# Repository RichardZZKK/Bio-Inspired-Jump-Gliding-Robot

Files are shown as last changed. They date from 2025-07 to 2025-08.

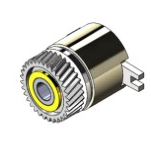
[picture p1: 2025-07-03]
motor-to-electromagnetic clutch connection design/Assembled servo.png

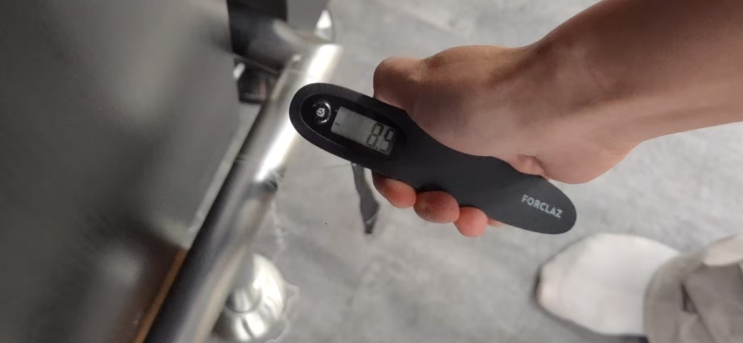
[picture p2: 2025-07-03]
photos taken during the project/testing the maximum tensile strength in 0.5mm.jpg

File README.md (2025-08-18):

# Bio-Inspired-Jump-Gliding-Robot

Inspired by recent studies of planetary jump robots and bio-inspired gliding mechanisms, we propose a novel robot capable of both repeated elastic-powered jumps and controlled gliding. The key innovation is the use of carbon fiber strips for energy storage and actuation, enabling jumping launches and mid-air wing deployment. So far, we detail the system architecture, mathematical modeling, and challenges encountered in the realization of this hybrid jump-gliding robot.

Our main goal was to design a robot capable of repeated jumps and gliding, expanding its operational range and adaptability. Our innovation lies in the integration of a carbon fiber strip-powered jumping mechanism with a deployable wing gliding system. Unlike prior robots that typically perform single-use or limited jumps, and compared to conventional flying robots, our design offers higher reliability and significantly lower energy consumption. So far, we detail the system architecture, mathematical modeling, and challenges encountered in the realization of this hybrid jump-gliding robot.

# So far, we have completed the following work...

<span style="font-size:20px;">And further tasks are ongoing and being continuously updated until the project is completed.</span>

[Interm Review PPT 01](https://sutdapac-my.sharepoint.com/:p:/g/personal/zheng_zhang_mymail_sutd_edu_sg/EfePilspKQ1Gtsf8nFOdvJUBf0UiOSyuQf-EtbSmFA2OlQ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)

[Interm Technical Report 01](https://github.com/RichardZZKK/Bio-Inspired-Jump-Gliding-Robot/blob/main/Interim%20Technical%20Report%2001.pdf)

[Final PPT](https://github.com/RichardZZKK/Bio-Inspired-Jump-Gliding-Robot/blob/main/Final%20Presentation.pdf)

[Final Technical Report 01](https://github.com/RichardZZKK/Bio-Inspired-Jump-Gliding-Robot/blob/main/Final%20Technical%20Report.pdf)

- Jump Solution Selection: After comparing different jump actuation mechanisms, we found that biomimetic legged or complex multi-link jumping structures, are not suitable for our intended application. These mechanisms are generally too heavy and not conducive to achieving lightweight design and effective gliding. Based on further research, we selected the carbon fiber strip compression jumping mechanism, which best meets our requirements for both performance and weight.

<div align="center">
<table>
  <tr>
    <td>
      
    </td>
    <td>
      
    </td>
  </tr>
</table>
</div>

<p align="center">
  
</p>
  
- Release Mechanism: The release mechanism works by using an electromagnetic clutch* to quickly connect or disconnect the winch from the motor. During energy storage, the motor—through the engaged clutch—pulls the UHMWPE line to stretch the carbon fiber strip and store elastic energy. When the target tension is reached, power to the clutch is cut, instantly disconnecting the winch from the motor. This allows the stored energy to be released rapidly, enabling the jump, while protecting the motor from any sudden forces or backlash during the release.
<div align="center">
<table>
  <tr>
    <td>
      
    </td>
    <td>
      
    </td>
  </tr>
</table>
</div>

- Design of Jump Energy Storage and Release: Utilizes a winch motor to tension a Ultra-high-molecular-weight polyethylene(UHMWPE) line attached to carbon fiber strips, storing elastic potential energy. 
<div align="center">
<table>
  <tr>
    <td>
      
    </td>
    <td>
      
    </td>
  </tr>
</table>
</div>

- Design of Gliding Mechanism: Wings are deployed at the apex of each jump, either by electronic control or mechanical triggering.
*An electromagnetic clutch engages or disengages power transmission between two shafts by using electromagnetic force. When current is applied, the clutch connects the shafts; when current is removed, the connection is released.
<div align="center">
<table>
  <tr>
    <td>
      
    </td>
    <td>
      
    </td>
  </tr>
</table>
</div>

<div align="center">
<table>
  <tr>
    <td>
      
    </td>
    <td>
      
    </td>
  </tr>
</table>
</div>

## Electronics Design

### MCU & Power

- **MCU**: Arduino Nano 33 BLE Sense Rev2 (NINA B306 + Cortex‑M4F)  
- **Input Voltage**: 3.3 V (all I/O 3.3 V TTL)  
- **Key Specs**: 64 MHz, 1 MB Flash + 256 kB RAM; BLE 5.0; onboard DC‑DC converter; BMI270/BMM150 9‑axis IMU  
- **Power Supply**:  
  - **Motor**: 2 × 3.7 V, 100 mAh Li‑ion battery packs in series  
  - **Clutch**: 5 × 3.7 V, 100 mAh Li‑ion battery packs in series  
  - **Board**: 1 × 3.7 V, 100 mAh Li‑ion battery pack

### Bill of Materials

| # | Component |
|---|---|
| 1 | Arduino Nano 33 BLE Sense Rev2 |
| 2 | On‑board 9‑axis IMU (BMI270 + BMM150) |
| 3 | 6 V DC motor + MOSFET driver |
| 4 | 24 V electromagnetic clutch + MOSFET driver |
| 5 | 2 × Hobby servos |
| 6 | Power modules (3.3 V, 6 V, 24 V rails) |
| 7 | Assorted wiring |

### Pin Assignment

| Function | Arduino Pin  | Description |
|---|---|---|
| Motor MOSFET Gate | D3 | Drives 6 V DC motor |
| Clutch MOSFET Gate | D4 | Drives 24 V electromagnetic clutch |
| Servo PWM Signals | D9, D10 | Hobby servo control (future gliding) |
| Limit Switch Inputs | D2, D5… | End‑stop switches |
| I²C (BMI270 IMU) | SDA(A4), SCL(A5) | On‑board 9‑axis sensor |
| BLE UART | Serial1 | UART on NINA B306 (debug/servo) |
| Power & Ground | VIN, GND | 3.3 V input & common ground |

---

### Code Overview
#### File Structure

```plaintext
src/
└── Jump-Gliding-Robot/
    ├── Jump-Gliding-Robot.ino    # Main application entrypoint
    ├── include.h                 # Macros & Lobot protocol constants
    └── SerialServo.h             # Lobot serial‑servo driver implementations
```

Below is an annotated overview of `Jump-Gliding-Robot.ino`.  

#### 1. Include Statements & Libraries

```cpp
#include <ArduinoBLE.h>
#include "Arduino_BMI270_BMM150.h"
#include <Wire.h>
#include <Servo.h>
#include "include.h"
#include "SerialServo.h"
```
* ArduinoBLE: BLE Low Energy support
* Arduino_BMI270_BMM150: On‑board 9‑axis IMU (BMI270 + BMM150)
* Wire: I²C bus for IMU
* Servo: Hobby servo control
* include.h / SerialServo.h: Project‑specific macros & Lobot servo driver

#### 2. Global Objects & Configuration
```cpp
Servo servo1, servo2;

BLEService sensorService("180F");
BLEByteCharacteristic servoCommandCharacteristic("2A19", BLEWrite);
BLECharacteristic imuDataCharacteristic("2A58", BLENotify, 36);

const int motorPin   = 3;       // MOSFET gate for 6 V motor
const int clutchPin  = 4;       // MOSFET gate for 24 V clutch
const long interval  = 50;      // IMU send interval (ms)
unsigned long previousMillis = 0;
```
* servo1/servo2: Reserved for future gliding control
* BLEService & Characteristics:
* 2A19 (write) for receiving commands
* 2A58 (notify) for streaming IMU data
* Pins & Timing: Define motor/clutch pins and non‑blocking timer

#### 3. setup() — Initialization
```cpp
void setup() {
  Serial1.begin(115200);
  Wire.begin();
  servo1.attach(9);
  servo2.attach(10);

  pinMode(motorPin, OUTPUT);
  pinMode(clutchPin, OUTPUT);
  digitalWrite(motorPin, LOW);
  digitalWrite(clutchPin, LOW);

  if (!BLE.begin()) while (1);
  BLE.setLocalName("Nano33BLE_IMU");
  BLE.setAdvertisedService(sensorService);
  sensorService.addCharacteristic(servoCommandCharacteristic);
  sensorService.addCharacteristic(imuDataCharacteristic);
  BLE.addService(sensorService);
  BLE.advertise();

  if (!IMU.begin()) while (1);
}
```
* Serial & I²C: Serial1 for debugging/servo, Wire for IMU
* Servo Pins: Attach D9/D10
* Motor/Clutch: Initialize outputs to LOW
* BLE: Start, configure service & characteristics, begin advertising
* IMU: Begin BMI270/BMM150 sensor

#### 4. sendIMUData() — Packaging & Sending IMU
```cpp
void sendIMUData() {
  float ax, ay, az, gx, gy, gz, mx, my, mz;

  if (IMU.accelerationAvailable())    IMU.readAcceleration(ax, ay, az);
  if (IMU.gyroscopeAvailable())       IMU.readGyroscope(gx, gy, gz);
  if (IMU.magneticFieldAvailable())   IMU.readMagneticField(mx, my, mz);

  byte imuData[36];
  memcpy(imuData +  0, &ax, 4);
  memcpy(imuData +  4, &ay, 4);
  memcpy(imuData +  8, &az, 4);
  memcpy(imuData + 12, &gx, 4);
  memcpy(imuData + 16, &gy, 4);
  memcpy(imuData + 20, &gz, 4);
  memcpy(imuData + 24, &mx, 4);
  memcpy(imuData + 28, &my, 4);
  memcpy(imuData + 32, &mz, 4);

  imuDataCharacteristic.writeValue(imuData, 36);
}
```
* Selective Reads: Only read available axes
* Data Layout: ax, ay, az, gx, gy, gz, mx, my, mz (4 bytes each)
* Notify: Send 36 bytes over BLE

#### 5. loop() — Main Command Handler
```cpp
void loop() {
  BLEDevice central = BLE.central();
  if (!central || !central.connected()) return;

  byte command = 0;
  if (servoCommandCharacteristic.written()) {
    command = servoCommandCharacteristic.value();
  }

  if (command == 1) {
    // Pull rope & release for jumping
    digitalWrite(motorPin, HIGH);
    digitalWrite(clutchPin, HIGH);
    delay(5000);
    digitalWrite(motorPin, LOW);
    digitalWrite(clutchPin, LOW);
  }
  else if (command == 2) {
    // Test mode: keep motor & clutch powered
    digitalWrite(motorPin, HIGH);
    digitalWrite(clutchPin, HIGH);
  }
  else if (command == 3) {
    // Future gliding: move servos
    LobotSerialServoMove(Serial1, 1, 400, 800);
    LobotSerialServoMove(Serial1, 2, 400, 800);
  }
  else if (command == 4) {
    // Future gliding: move servos
    LobotSerialServoMove(Serial1, 1, 800, 400);
    LobotSerialServoMove(Serial1, 2, 800, 400);
  }

  // Periodic IMU report
  if (millis() - previousMillis >= interval) {
    previousMillis = millis();
    sendIMUData();
  }
}
```
* Checks BLE connection
* Non‑blocking command read & dispatc
* Jump sequence, test mode, future gliding
* Periodic IMU data send

# Ongoing efforts focus on: 
* Improving mechanical efficiency and alignment, 
* Optimizing the wing deployment strategy, 
* Designing and testing closed-loop feedback and control, 
* Validating the robot in more varied and realistic test scenarios.

Authors:
[RichardZZKK](url)
[llz077](url)
[Ianthomas-gee](url)

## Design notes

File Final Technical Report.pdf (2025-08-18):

# A Bio-Inspired Jump-Gliding Robot for Planetary and Terrestrial Exploration

Final Technical Report
Zhang Zheng, Liu Lizhi, Xu Yukun
Engineering Product Development, Singapore University of Technology and Design Singapore
zheng_zhang@mymail.sutd.edu.sg lizhi_liu@mymail.sutd.edu.sg yukun_xu@mymail.sutd.edu.sg

Abstract—Inspired by recent studies of planetary jump robots and bio-inspired gliding mechanisms, we propose a novel robot capable of both repeated elastic-powered jumps and controlled gliding. The key innovation is the use of carbon fiber strips for energy storage and actuation, enabling jumping launches and mid-air wing deployment. So far, we detail the system architecture, mathematical modelling, and challenges encountered in the realization of this hybrid jump-gliding robot.
Index Terms—Jump-gliding robot; elastic-powered jumping; carbon fiber; gliding mechanism.
I. INTRODUCTION
Our main goal was to design a robot capable of repeated jumps and gliding, expanding its operational range and adaptability. Our innovation lies in the integration of a carbon fiber strip-powered jumping mechanism with a deployable wing gliding system. Unlike prior robots that typically perform single-use or limited jumps, and compared to conventional flying robots, our design offers higher reliability and significantly lower energy consumption. So far, we detail the system architecture, mathematical modeling, and challenges encountered in the realization of this hybrid jump-gliding robot.

II. SYSTEM DESIGN
Solution Selection: After comparing different jump actuation mechanisms, we found that biomimetic legged or complex multi-link jumping structures are not suitable for our intended application. These mechanisms are generally too heavy and not conducive to achieving lightweight design and effective gliding. Based on further research, we selected the carbon fiber strip compression jumping mechanism, which best meets our requirements for both performance and weight. Release Mechanism: The release mechanism works by using an electromagnetic clutch* to quickly connect or disconnect the winch from the motor. During energy storage, the motor— through the engaged clutch—pulls the UHMWPE line to stretch the carbon fiber strip and store elastic energy. When the target tension is reached, power to the clutch is cut, instantly disconnecting the winch from the motor. This allows the stored energy to be released rapidly, enabling the jump, while protecting the motor from any sudden forces or backlash during the release.
Design of Jump Energy Storage and Release: Utilizes a winch motor to tension an Ultra-high-molecular-weight polyethylene (UHMWPE) line attached to carbon fiber strips, storing elastic potential energy.
Electromagnetic Clutch
For the release mechanism, we employed an electromagnetic clutch to control the tightening and release of the Ultra-high-molecular-weight polyethylene (UHMWPE). To ensure proper alignment of the UHMWPE during retraction, a dedicated holder frame (Fig. 1) was designed to accommodate both the servo motor and the electromagnetic clutch.

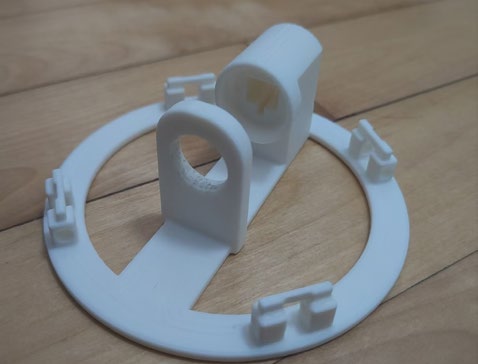
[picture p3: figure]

Fig. 1. Holder frame
In addition, a secondary frame was introduced to support the winch shaft, enabling it to counteract the downward tensile force exerted by the rope. Overall, the servo motor is rigidly connected to the electromagnetic clutch via a coupling component (Fig. 2.), and both are mounted within the frame. The gear portion of the clutch is exposed externally (Fig. 3.), where it engages with a custom-designed internal-toothed shaft connector. This shaft passes through a bearing, which is secured on the secondary frame (Fig. 4.). The shaft itself is designed with a small through-hole (Fig. 5.), through which the UHMWPE is threaded and fixed by knotting, enabling controlled winding and unwinding.

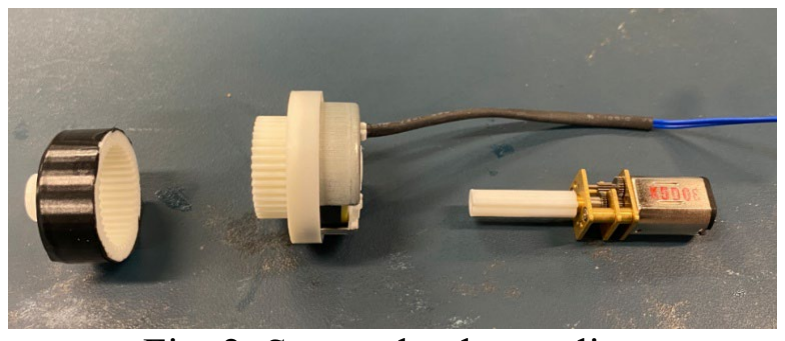
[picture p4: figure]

Fig. 2. Servo-clutch coupling

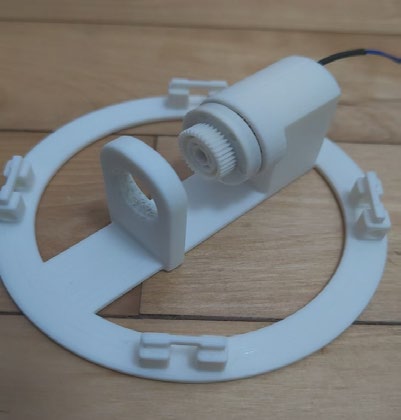
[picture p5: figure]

Fig. 3. Clutch placement

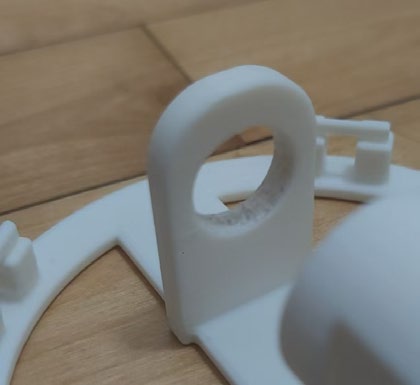
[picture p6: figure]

Fig. 4. Bearing support

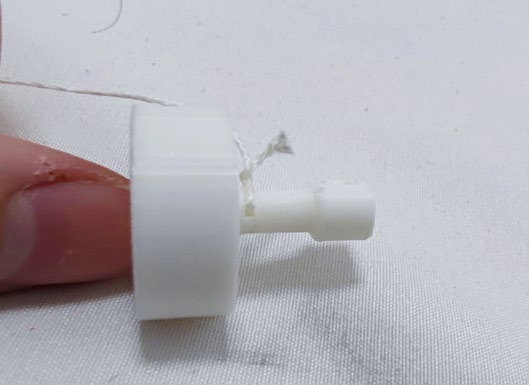
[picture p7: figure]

Fig. 5. Shaft with through-hole

The design underwent several iterations before reaching the final version:
First Version (Fig. 6.): The initial frame did not adequately secure the servo motor and clutch. During testing, once the UHMWPE was tensioned to a certain degree, the shaft connector would detach from the frame. Although adhesive was applied to fix the clutch, the shaft of the connector lacked sufficient strength and eventually fractured under load.

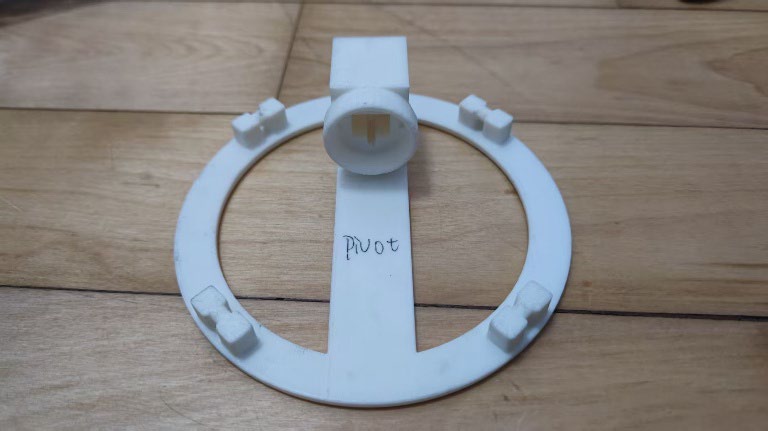
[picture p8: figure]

Fig. 6. First version of upper plate design

Second Version (Fig. 7a, b): The frame dimensions were revised, and a larger supporting frame was added to house the bearing. However, this resulted in a bulkier structure, and the shaft connector continued to experience detachment.

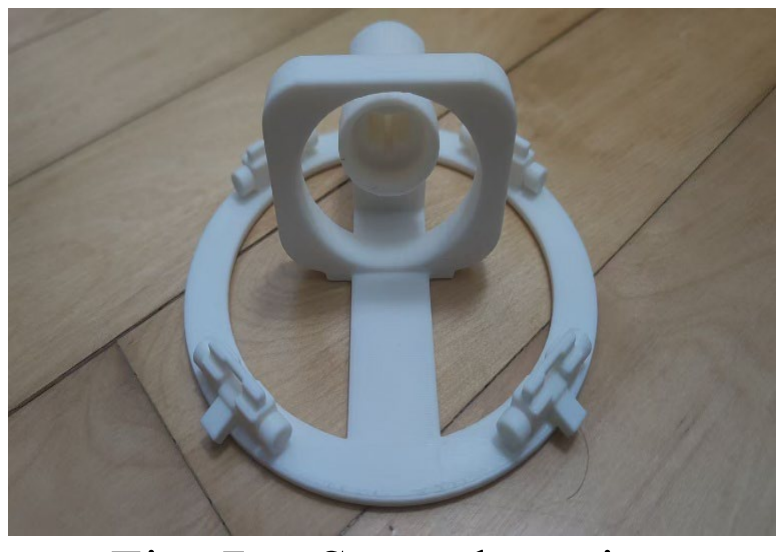
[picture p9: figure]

Fig. 7. a Second version

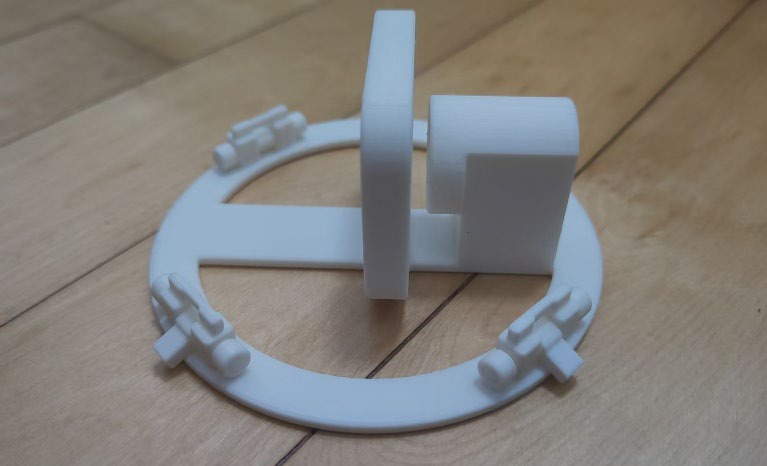
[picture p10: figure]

Fig. 7. b. Second version

Third Version: The geometry of the winch frame was further optimized by adjusting both the frame spacing and shaft dimensions of the connector. In this iteration, the clutch and bearing were reliably secured, preventing detachment. The mechanism successfully supported the complete jumping process and enabled repeatable actuation.
Gliding Mechanism
Design: The gliding wings are constructed using multiple carbon fiber rods as the structural framework, over which a high-strength polymer kite fabric is stitched to provide lift during gliding. A dedicated wing mounting frame was also designed to secure the wings to the upper plate of the robot. Preliminary Concept: In the initial configuration, the wings remain folded in a retracted state, hanging naturally downward. Upon reaching the apex of the jump and during the onset of descent, the wings deploy passively under aerodynamic reaction forces, thereby initiating gliding.

Design of Gliding Mechanism: Wings are deployed at the apex of each jump, either by electronic control or mechanical triggering.
*An electromagnetic clutch engages or disengages power transmission between two shafts by using electromagnetic force. When current is applied, the clutch connects the shafts; when current is removed, the connection is released.

III. MODELING AND ANALYSIS

Energy Storage:

# Eelastic =∫ FF(xx)dd xxmmmm

0
The above equation represents the idealized calculation of the elastic energy stored in our device, obtained by directly summing the discrete force measurements without considering energy losses. However, we found that results calculated using this method differ significantly from those obtained by the area-under-the-curve (integral) approach. In practical applications, it is more accurate to estimate the stored energy using the integral formulation shown below.

# Eelastic≈∑ FF(ii)+FF(ii+1)

2

nn−1

# ii=1 (xi+1-xi)

We define the stored elastic energy, Eelastic, as the total mechanical work done during the compression of the carbon fiber spring. Specifically, the force–displacement relationship is nonlinear, and the energy is computed by integrating the measured force F(x) over the full compression distance xmax ,where F(x) is the measured force at displacement x, and xmax is the maximum compression. * The area under the force– displacement curve was obtained experimentally using a digital scale and ruler (see photos below), yielding an estimated elastic energy of approximately 15.2 J as shown in Fig. 8.

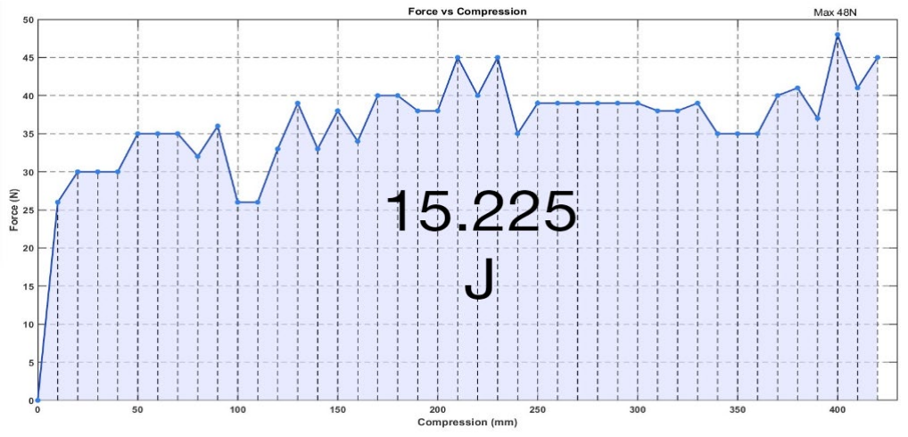
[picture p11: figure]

Fig. 8. Experimental force–displacement curve of the carbon-fiber spring
Theoretical Jump Height:

# Hideal= Eelastic Mtotal · g

The ideal jump height, Hideal, is estimated by equating the measured elastic potential energy to the gravitational potential energy required to elevate the total system mass. Specifically, where Eelastic is the experimentally measured elastic energy, Mtotal is the total mass of the jumping system, and g is the acceleration due to gravity. This equation assumes 100% conversion of stored elastic energy into vertical displacement, thus representing the upper bound of achievable jump height in the absence of energy losses.
Jump Height:

Hestimate=

# Eelastic · (1−Ddrag) · (1−βxy−βθ) · (1−xCoM)

# Mtotal · g

The jump height, Hestimate, accounts for various energy losses in the real system that are not reflected in the theoretical calculation. These losses include air drag (Ddrag), effects from non-vertical take-off angles (βxy), device rotation during take-off (βθ), and the influence of the center of mass position (XCoM). where:
Ddrag is the fractional energy loss due to air resistance during the jump
βxy and βθ represent losses caused by non-vertical take-off and device rotation, respectively
XCoM denotes the effect of the center of mass location on the device
Hestimate=Hideal · η
As it is difficult to measure or model all these loss factors accurately, we also employ a simplified approach by introducing an overall efficiency factor η, defined as the ratio of actual jump height to the theoretical value based on literature [12].
* For energy estimation, a force gauge was attached to the jumping device and incrementally stretched in the vertical direction. The force readings were visualized and recorded at each interval to generate a force–displacement curve. By calculating the area under this curve using the appropriate formula (numerical integration), we obtained an estimate of the stored elastic energy in the system.

IV.PROTOTYPE AND EXPERIMENTS
This section presents the preliminary prototype we fabricated based on our prior design and simulations, along with the initial experimental tests conducted on several of the model’s functional components.
A. Jumping Module
In the final prototype, four carbon‐fiber strips measuring 75 cm × 0.5 cm × 0.2 cm were employed as the elastic energy–storage elements of the jumping mechanism. The strip ends were secured using carbon‐fiber fabric and cloth‐based adhesive tape, and a 1.4 m–long ultra–high–molecular–weight polyethylene (UHMWPE) braided line was routed through the assembly to preload the strips.
Structural platforms: The upper and a lower circular platform, each with a diameter of 130 mm and a thickness of 3.5 mm. These platforms are connected by custom joints and 3D-printed connectors, which provide the structural support for the motor, clutch, and jumping mechanism. The lower platform also anchors the UHMWPE tensioning lines required for energy storage.
Electrical module: The actuation is driven by a 1:1000 high-torque DC motor, controlled by an Arduino Nano microcontroller. Power is supplied by eight 100 mAh lithium-polymer battery packs. The module also includes custom wiring and connectors to coordinate motor actuation and release control.
Jumping and release mechanism: The redesigned energy storage system, combined with the clutch–bearing release module, ensures repeatable high-energy jumps rather than one-time actuation.
The entire device employs extensive 3D-printed components and custom connectors, achieving a balance of light weight and mechanical robustness. In operation, the robot first stores elastic potential energy in the carbon-fiber strips, then rapidly releases it to propel the body upward.
The overall structure measures approximately 757 mm in length and 130 mm in width, the fully assembled jumping module has a mass of 173 g.
the prototype is shown in Fig. 9.

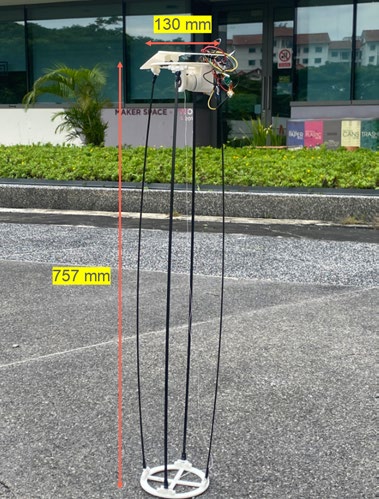
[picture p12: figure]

Fig. 9. The jumping module in the uncharged state, and in the charged with instantaneous‐release state

The operation of the jumping mechanism proceeds through four distinct phases, as illustrated in Fig. 10:
(a) Resting state: The carbon–fiber strips are straight and unstressed, with the UHMWPE line relaxed.(b) Energy storage: The motor–clutch assembly tensions the UHMWPE line, bending the carbon–fiber strips and storing elastic potential energy.(c) Release: The release mechanism disengages, enabling the stored energy to be rapidly converted into kinetic energy.(d) Take-off: The accumulated elastic energy propels the structure upward, lifting the module off the ground.

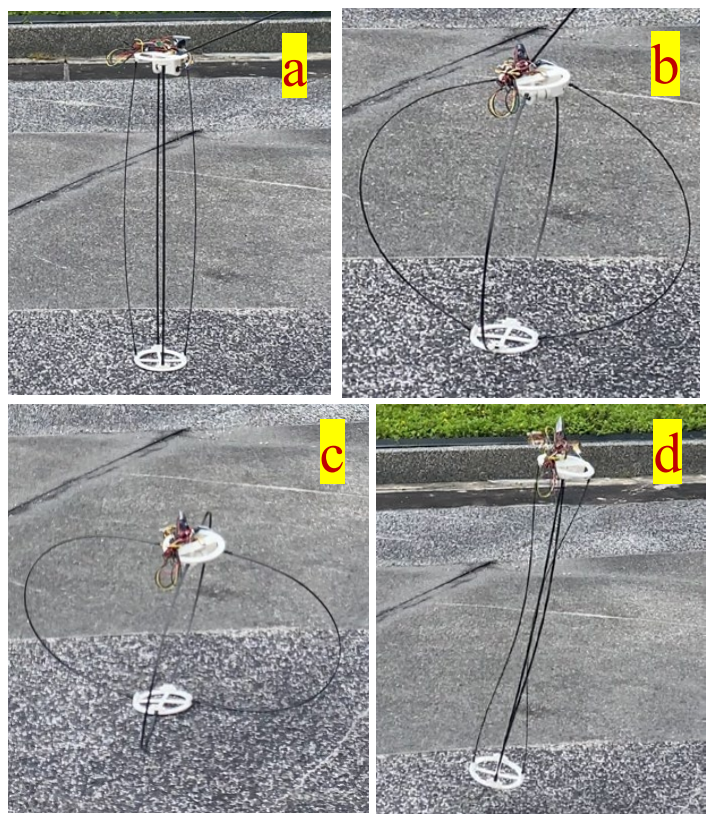
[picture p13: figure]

Fig. 10. Sequential operation of the jumping mechanism.

Experimental evaluation was conducted to verify the performance of the jumping module. The prototype achieved a maximum jump height of approximately 1.5 m, as shown in Fig. 11. Endurance testing demonstrated that the system can perform at least four consecutive jumps without structural damage. Under ideal conditions, the module is capable of repeated operation until the depletion of the onboard battery.

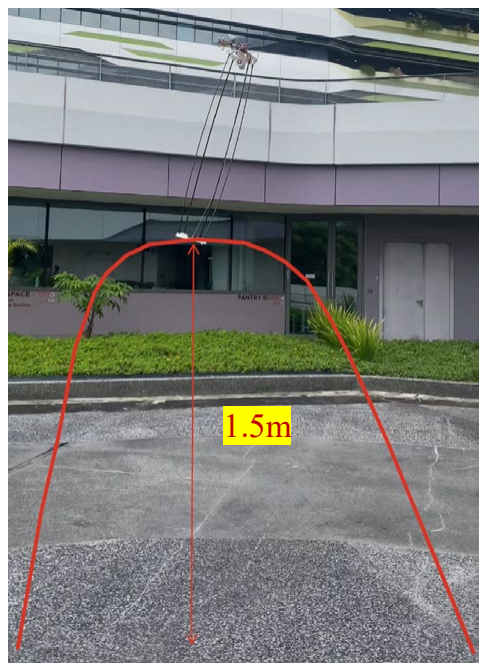
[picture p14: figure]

Fig. 11. Measured maximum jump height of the prototype (≈1.5 m)

A. Gliding Module
A preliminary gliding module was constructed to evaluate the feasibility of extending aerial motion following take-off. The structure employed carbon–fiber rods as the primary skeleton and was covered with a lightweight Icarex PC31 fabric, as shown in Fig. 12. This configuration provided a rigid yet lightweight wing frame suitable for integration with the jumping mechanism.

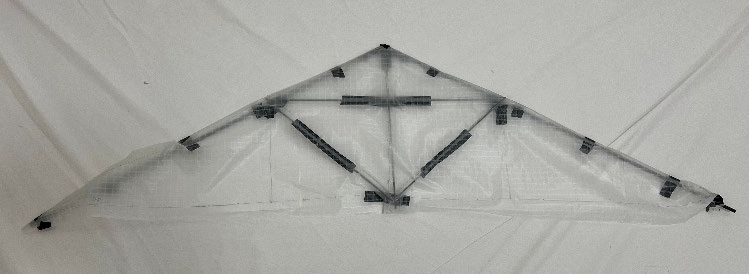
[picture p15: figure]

Fig. 12. Preliminary gliding module constructed using carbon–fiber rods and Icarex PC31 fabric Independent testing of the gliding module indicated that the prototype was capable of achieving stable passive gliding when deployed in isolation, as shown in Fig. 13. Although the present tests were limited in scope, the results demonstrate the potential of combining the jump module with the glider to achieve controlled jump–gliding locomotion.

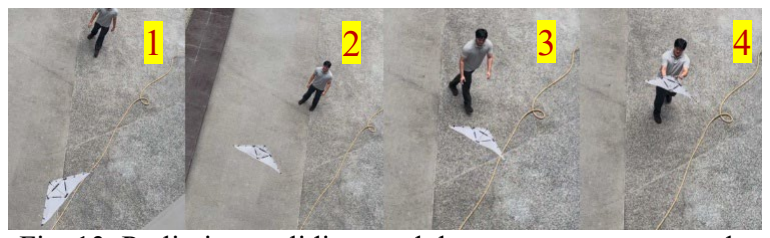
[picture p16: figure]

Fig. 13. Preliminary gliding module prototype constructed using carbon–fiber rods and Icarex PC31 fabric

V. CONCLUSION AND FUTURE WORK
In this work, we presented the design and prototyping of a bio-inspired jump–gliding robotic system. The proposed jumping mechanism, based on carbon-fiber elastic strips and a clutch–bearing release assembly, successfully achieved repeatable jumping performance, reaching heights of approximately 1.5 m. Unlike prior studies, which typically demonstrated only single-shot jumps due to irreversible structural deformation or limited energy-release mechanisms, our system has been experimentally validated to perform multiple consecutive jumps without structural failure. This marks a significant advancement in the domain of bio-inspired elastic jumping robots.
In parallel, a preliminary gliding module was developed using a carbon-fiber skeleton covered with Icarex PC31 fabric. Independent testing confirmed its capability to achieve passive gliding; however, full integration of the jumping and gliding subsystems has not yet been realized. The integration poses nontrivial challenges, including structural coupling, stability during transition, and control of aerodynamic surfaces. Future work will focus on the mechanical and control integration of the jumping and gliding modules to achieve seamless jump–gliding locomotion. Additional efforts will also be directed toward optimizing the energy efficiency, enhancing structural robustness, and exploring control strategies that enable stable aerial transitions. Successful realization of such integration would open the door to practical applications in extraterrestrial exploration, search-and-rescue missions, and operations in extreme or hazardous environments.

ACKNOWLEDGMENT
We are sincerely grateful to Professor Shao, Professor Pablo, the SUTD FabLab staff, and the STUD Dyson staff, whose generous guidance, unwavering support, and thoughtful feedback have been essential to our progress and success in this project.

REFERENCES
[1] A. Datar, C. Pan, M. Nazeri, and X. Xiao, “Toward wheeled mobility on vertically challenging terrain: Platforms, datasets, and algorithms,” arXiv Preprint, arXiv:2303.00998, Mar. 2023.
[2] Y. Gao, B. Su, L. Jiang, and F. Gao, “Multi-legged robots: progress and challenges,” Natl. Sci. Rev., vol. 10, no. 5, p. nwac214, Oct. 2022, doi:10.1093/nsr/nwac214.
[3] S. A. H. Mohsan, N. Q. H. Othman, Y. Li, M. H. Alsharif, and M. A. Khan, “Unmanned aerial vehicles (UAVs): practical aspects, applications, open challenges, security issues, and future trends,” Intell. Serv. Robot., vol. 16, no. 1, pp. 109–137, Jan. 2023, doi:10.1007/s11370-022-00452-4.
[4] P. Liljebäck, K. Y. Pettersen, Ø. Stavdahl, and J. T. Gravdahl, “Hybrid modelling and control of obstacle‐aided snake robot locomotion,” IEEE Trans. Robot., vol. 26, no. 5, pp. 781 – 799, Nov. 2010, doi:10.1109/TRO.2010.2056211.
[5] A. A. Transeth, K. Y. Pettersen, and Ø. Stavdahl, “A survey on snake robot modeling and locomotion,” Robotica, vol. 27, no. 2, pp. 271–284, Mar. 2009, doi:10.1017/S0263574709005414.
[6] A. Krishnan, J. J. Socha, P. P. Vlachos, and L. A. Barba, “Lift and wakes of flying snakes,” Phys. Fluids, vol. 26, no. 3, Art. no. 031901, Mar. 2014, doi:10.1063/1.4866444.
[7] J. J. Socha, “Gliding Flight in Chrysopelea: Turning a Snake into a Wing,” Integr. Comp. Biol., vol. 51, no. 6, pp. 969–982, Dec. 2011, doi:10.1093/icb/icr092.
[8] E. W. Hawkes, C. Xiao, R.-A. Peloquin, C. Keeley, M. R. Begley, M. T. Pope, and G. Niemeyer, “Engineered jumpers overcome biological limits via work multiplication,” Nature, vol. 604, no. 7907, pp. 657– 662, Apr. 2022, doi:10.1038/s41586-022-04606-3.
[9] Iess L, Rappaport NJ, Jacobson RA, Racioppa P, Stevenson DJ, Tortora P, Armstrong JW, Asmar SW. Gravity field, shape, and moment of inertia of Titan. Science. 2010 Mar 12;327(5971):1367-9. doi: 10.1126/science.1182583. PMID: 20223984.
[10] Fulchignoni M, Ferri F, Angrilli F, Ball AJ, Bar-Nun A, Barucci MA, Bettanini C, Bianchini G, Borucki W, Colombatti G, Coradini M, Coustenis A, Debei S, Falkner P, Fanti G, Flamini E, Gaborit V, Grard R, Hamelin M, Harri AM, Hathi B, Jernej I, Leese MR, Lehto A, Lion Stoppato PF, López-Moreno JJ, Mäkinen T, McDonnell JA, McKay CP, Molina-Cuberos G, Neubauer FM, Pirronello V, Rodrigo R, Saggin B, Schwingenschuh K, Seiff A, Simões F, Svedhem H, Tokano T, Towner MC, Trautner R, Withers P, Zarnecki JC. In situ measurements of the physical characteristics of Titan's environment. Nature. 2005 Dec 8;438(7069):785-91. doi: 10.1038/nature04314. Epub 2005 Nov 30. PMID: 16319827.
[11] Won Dong Shin et al 2019 Bioinspir. Biomim.14 056009
[12] F. Zhao, W. Wang, J. Zhang, J. Wyrwa, and F. Sun, "Aerodynamic Characteristics and Pitching Adjusting Mechanism of the Flying Squirrel With Deployed Patagium," IEEE Access, vol. 7, pp. 185554– 185565, 2019, doi: 10.1109/ACCESS.2019.2961451. Demonstration of a Flying-Squirrel-Inspired Jumping Robot with Two Modes," Applied Sciences, vol. 11, no. 8, p. 3362, 2021, doi: 10.3390/app11083362.

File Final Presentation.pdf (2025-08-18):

# A Bio-Inspired Jump-Gliding Robot

## Team Sigma Tree - Zhang Zheng - Liu Lizhi - Xu Yukun

# Motivation

# Do something cool, something no one ever done before ! Always exploring !

# Overview

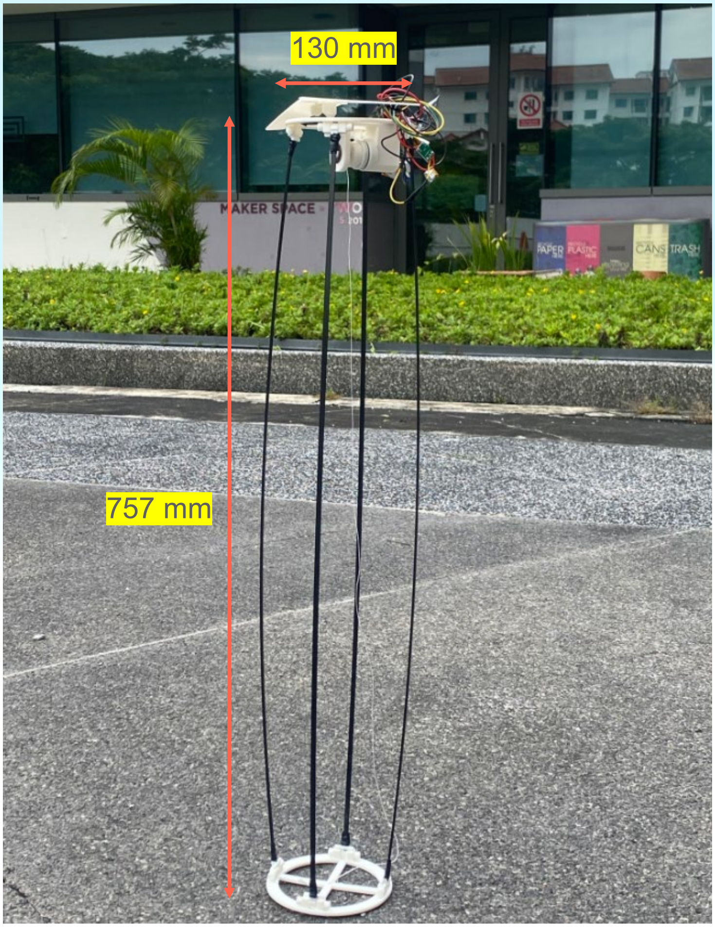
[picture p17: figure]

Upper Platform
- Bearing
- Clutch
- Motor
- Connector

Electrical Module
- Battery
- Arduino Nano
- Wires

Jumping Module
- Carbon fiber rod
- Ultra-High-Molecular-Weight Polyethylene

Lower Platform
- Connection structure

# - Release Mechanism - Testing & Performance

# Jumping Moudule

# Release Mechanism

# Others Only for One Time ！

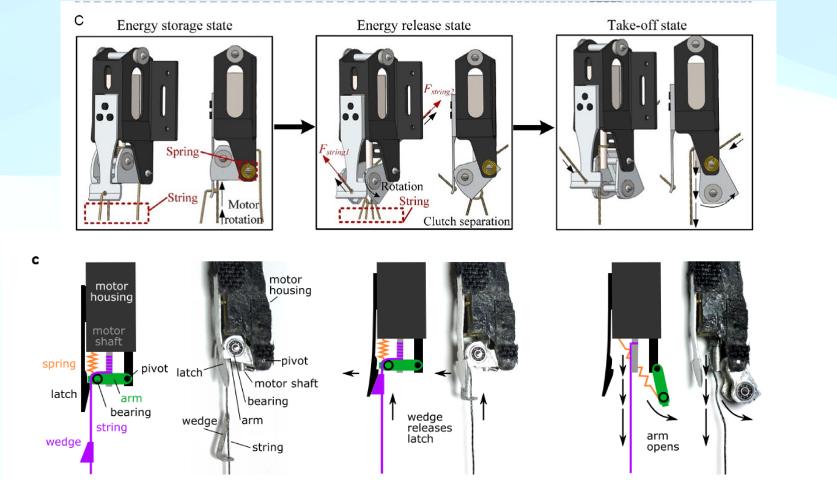
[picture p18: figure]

# Release Mechanism

# We can do many times ！

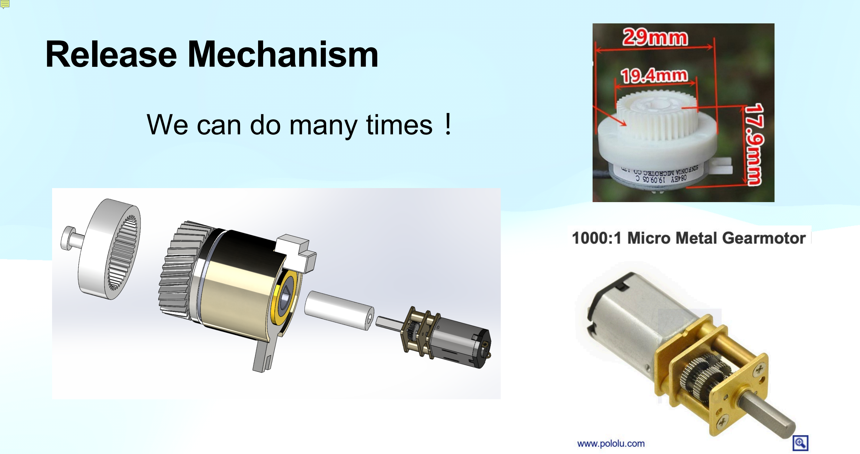
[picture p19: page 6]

# Release Mechanism

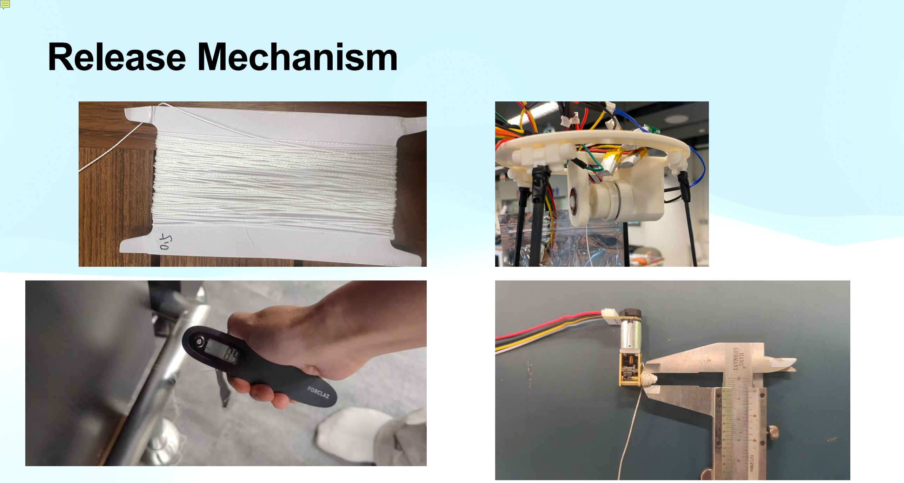
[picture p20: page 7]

# Iteration

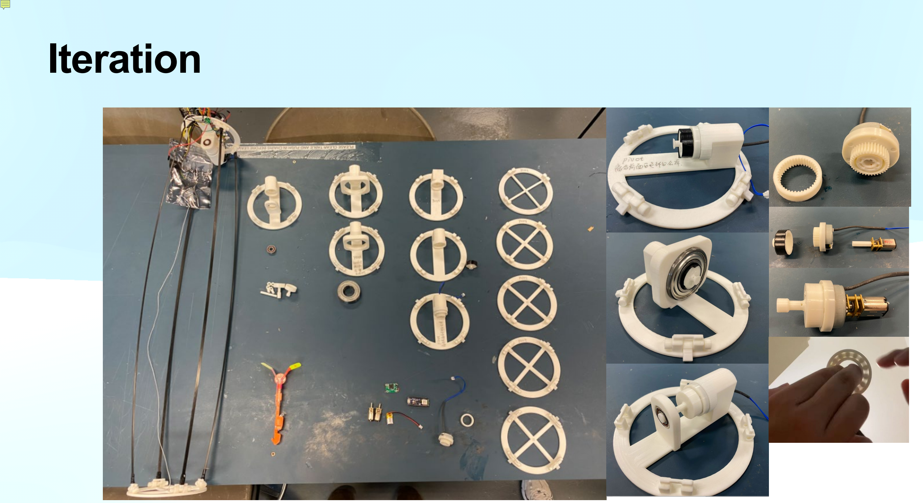
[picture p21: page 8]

# Release Mechanism

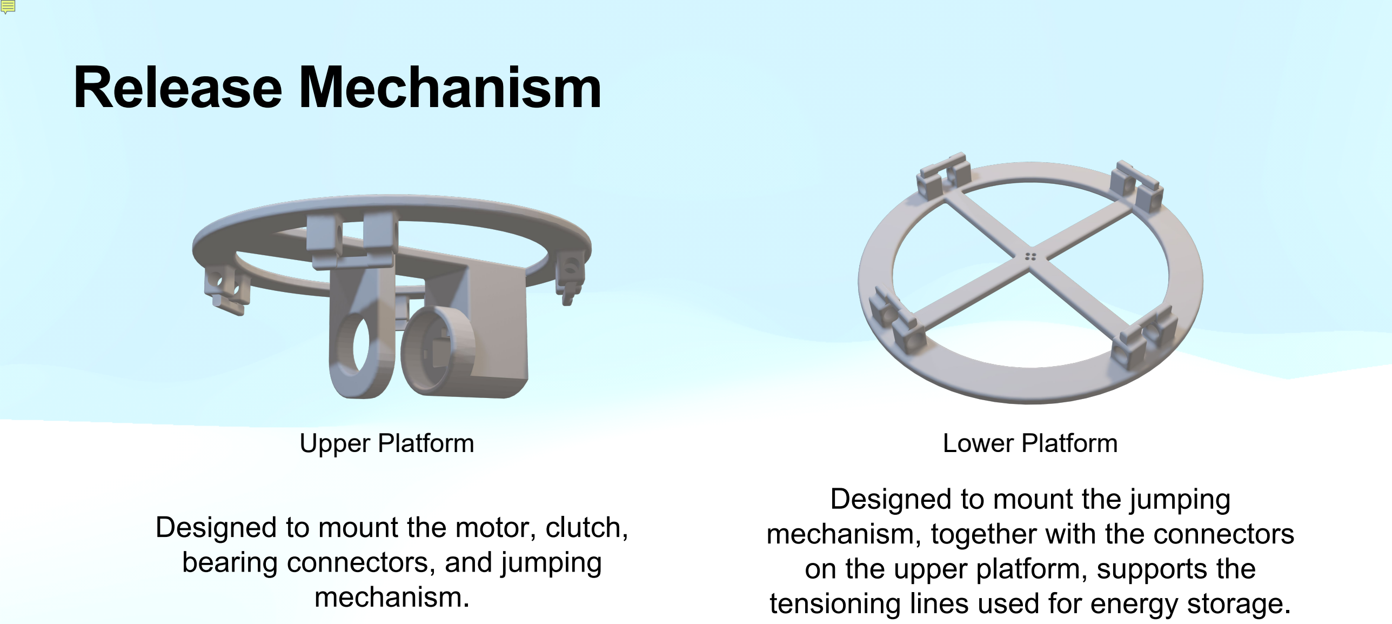
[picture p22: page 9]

Upper Platform | Lower Platform

Designed to mount the motor, clutch, bearing connectors, and jumping mechanism.

Designed to mount the jumping mechanism, together with the connectors on the upper platform, supports the tensioning lines used for energy storage.

# Release Mechanism

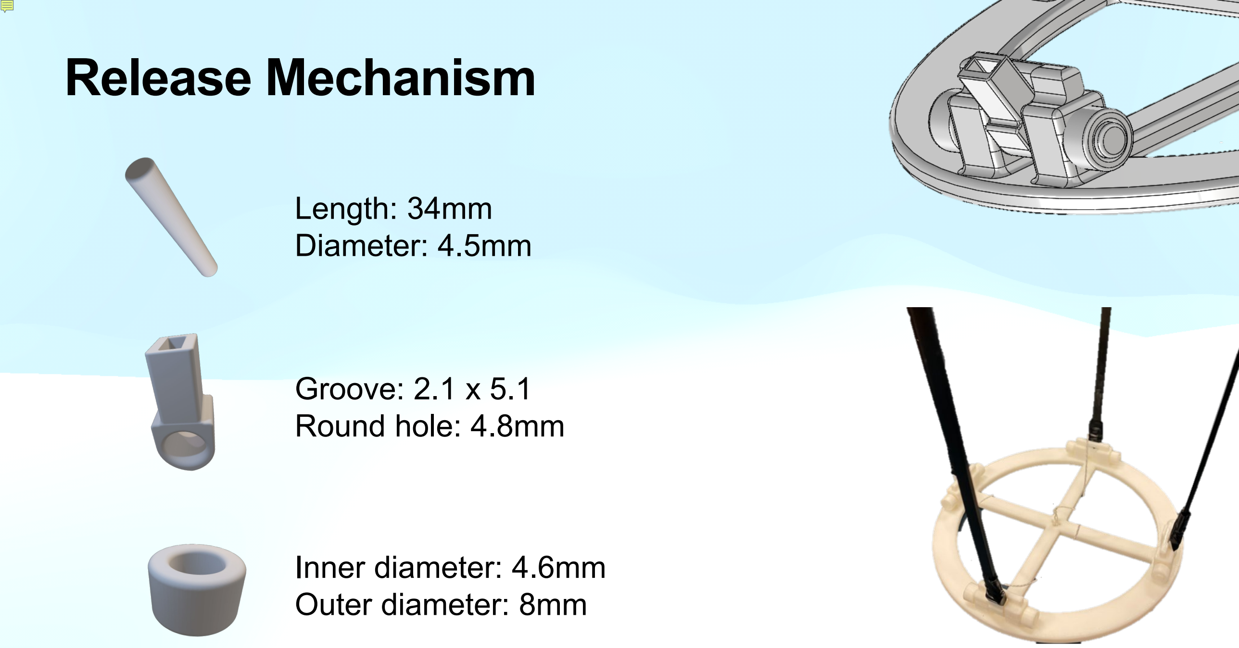
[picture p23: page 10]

## Length: 34mm Diameter: 4.5mm

## Groove: 2.1 x 5.1 Round hole: 4.8mm

## Inner diameter: 4.6mm Outer diameter: 8mm

# Release Mechanism

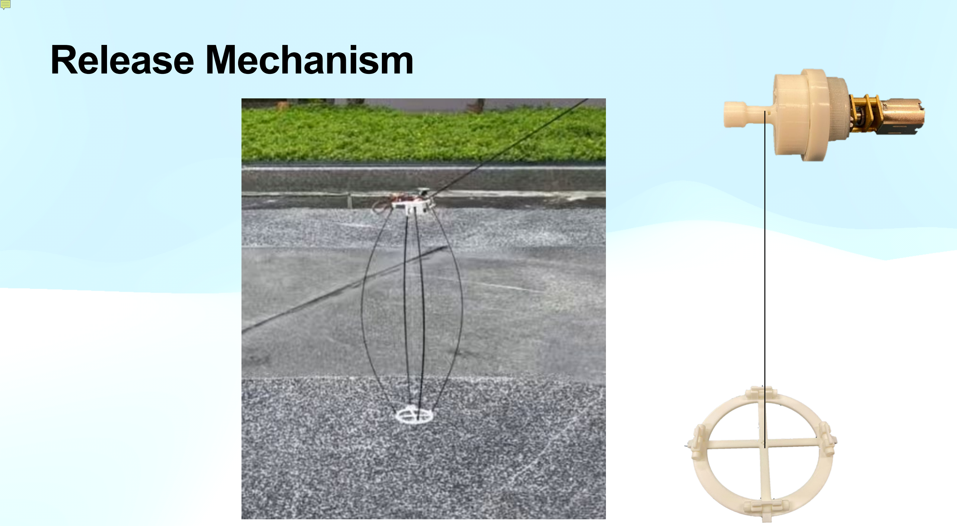
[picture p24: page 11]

# Testing & Performance

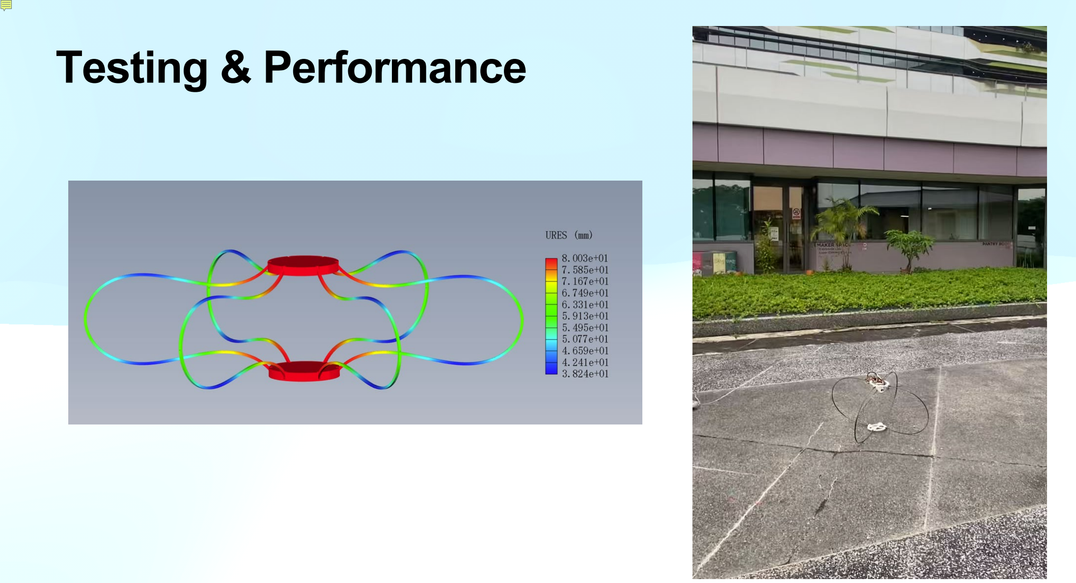
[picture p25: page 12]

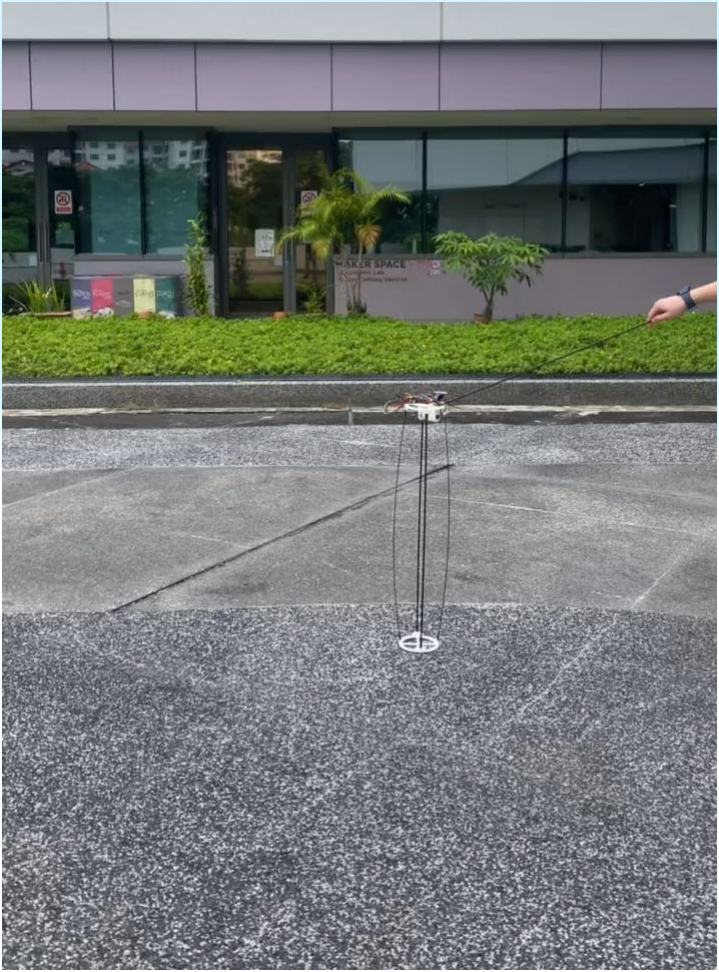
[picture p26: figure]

2m

1.17s

1.95s

# Testing & Performance

# Gliding Module


# MMtotal = 175 g

Components | Mass [g] | Amount | Total Mass [g]
Carbon Fiber Jumper | 64.0 | 1 | 64.0
EM Clutch | 23.0 | 1 | 23.0
Servo Motor | 16.0 | 1 | 16.0
Battery Pack | 1.2 | 8 | 13.6
Arduino Nano 33 Ble Rev2 | 6.1 | 1 | 6.1
Electrical Wires | 15 | 1 | 15
Gliding Wing | 25.0 | 2 | N.A
Connection Structure | 35.3 | 4 | 35.3


# Video

# Summary

# - Redesigned Energy Storage System - Custom Connectors - Extensive Use of 3D Printing - Lightweight Yet Strong

# Potential Application

# - Low-gravity extraterrestrial exploration - Search-and-rescue in extreme environments - Exploration in remote or dangerous areas

# Reference

[1] Datar, C. Pan, M. Nazeri, and X. Xiao, “Toward wheeled mobilityon vertically challenging terrain: Platforms, datasets, and algorithms,”arXiv Preprint, arXiv:2303.00998, Mar. 2023.
[2] Y. Gao, B. Su, L. Jiang, and F. Gao, “Multi-legged robots: progressand challenges,” Natl. Sci. Rev., vol. 10, no. 5, p. nwac214, Oct. 2022, doi:10.1093/nsr/nwac214.
[3] S. A. H. Mohsan, N. Q. H. Othman, Y. Li, M. H. Alsharif, andM. A. Khan, “Unmanned aerial vehicles (UAVs): practical aspects, applications, open challenges, security issues, and future trends,” Intell. Serv. Robot., vol. 16, no. 1, pp. 109–137, Jan. 2023, doi:10.1007/s11370-022-00452-4.
[4] P. Liljebäck, K. Y. Pettersen, Ø. Stavdahl, and J. T. Gravdahl, “ Hybrid modelling and control of obstacle ‐aided snake robot locomotion,” IEEE Trans. Robot., vol. 26, no. 5, pp. 781–799, Nov. 2010,

doi:10.1109/TRO.2010.2056211.
[5]A. A. Transeth, K. Y. Pettersen, and Ø. Stavdahl, “A survey on snake robot modeling and locomotion,” Robotica, vol. 27, no. 2, pp. 271–284, Mar. 2009, doi:10.1017/S0263574709005414.
[6]A. Krishnan, J. J. Socha, P. P. Vlachos, and L. A. Barba, “Lift and wakes of flying snakes,” Phys. Fluids, vol. 26, no. 3, Art. no. 031901, Mar. 2014, doi:10.1063/1.4866444.

# Reference

[7]J. J. Socha, “Gliding Flight in Chrysopelea: Turning a Snake into a Wing,” Integr. Comp. Biol., vol. 51, no. 6, pp. 969–982, Dec. 2011, doi:10.1093/icb/icr092.
[8]E. W. Hawkes, C. Xiao, R.-A. Peloquin, C. Keeley, M. R. Begley, M. T. Pope, and G. Niemeyer, “Engineered jumpers overcome biological limits via work multiplication,” Nature, vol. 604, no. 7907, pp. 657–662, Apr. 2022, doi:10.1038/s41586-022-04606-3.
[9]Iess L, Rappaport NJ, Jacobson RA, Racioppa P, Stevenson DJ, Tortora P, Armstrong JW, Asmar SW. Gravity field, shape, and moment of inertia of Titan. Science. 2010 Mar 12;327(5971):1367-9. doi: 10.1126/science.1182583. PMID: 20223984.
[10]Fulchignoni M, Ferri F, Angrilli F, Ball AJ, Bar-Nun A, Barucci MA, Bettanini C, Bianchini G, Borucki W, Colombatti G, Coradini M, Coustenis A, Debei S, Falkner P, Fanti G, Flamini E, Gaborit V, Grard R, Hamelin M, Harri AM, Hathi B, Jernej I, Leese MR, Lehto A, Lion Stoppato PF, López-Moreno JJ, Mäkinen T, McDonnell JA, McKay CP, Molina-Cuberos G, Neubauer FM, Pirronello V, Rodrigo R, Saggin B, Schwingenschuh K, Seiff A, Simões F, Svedhem H, Tokano T, Towner MC, Trautner R,

# Reference

Withers P, Zarnecki JC. In situ measurements of the physical characteristics of Titan's environment. Nature. 2005 Dec 8;438(7069):785-91. doi: 10.1038/nature04314. Epub 2005 Nov 30. PMID: 16319827 [11]Won Dong Shin et al 2019 Bioinspir. Biomim.14 056009
[12]F. Zhao, W. Wang, J. Zhang, J. Wyrwa, and F. Sun, "Aerodynamic Characteristics and Pitching Adjusting Mechanism of the Flying Squirrel With Deployed Patagium," IEEE Access, vol. 7, pp. 185554– 185565, 2019, doi: 10.1109/ACCESS.2019.2961451. Demonstration of a Flying-Squirrel-Inspired Jumping Robot with Two Modes," Applied Sciences, vol. 11, no. 8, p. 3362, 2021, doi: 10.3390/app11083362.

# Thank you !

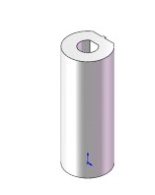
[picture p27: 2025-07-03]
motor-to-electromagnetic clutch connection design/Inner servo connector.png

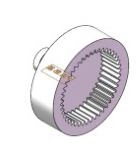
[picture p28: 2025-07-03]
motor-to-electromagnetic clutch connection design/Outer servo connector.png

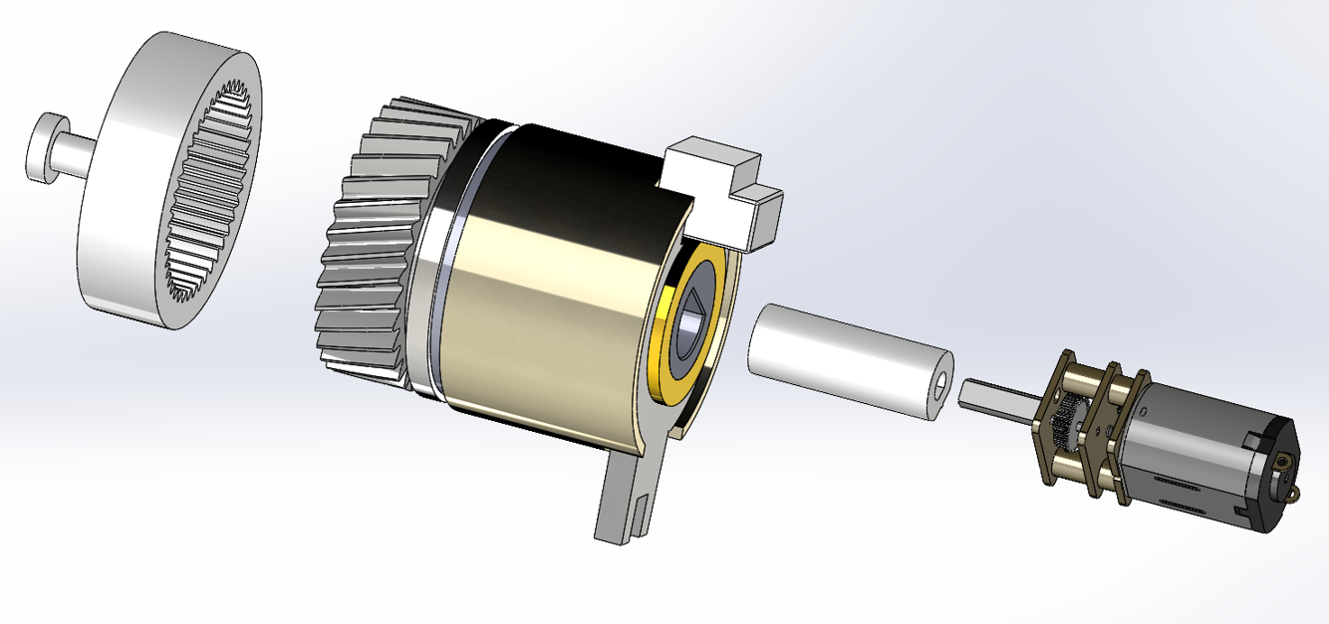
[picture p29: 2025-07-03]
motor-to-electromagnetic clutch connection design/Assmbled with connector.png

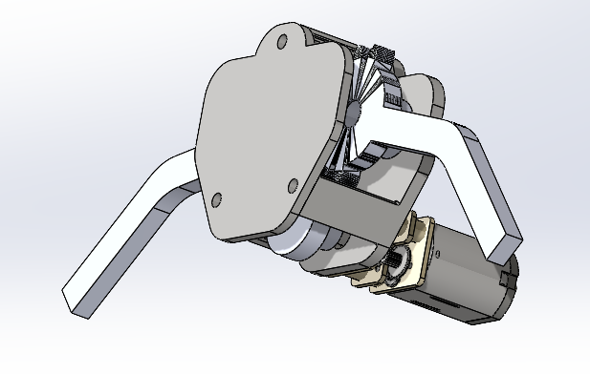
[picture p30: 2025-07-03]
initial guessing of gliding mechanism/motor controlled wing mechanism/Wing Mechanism.png

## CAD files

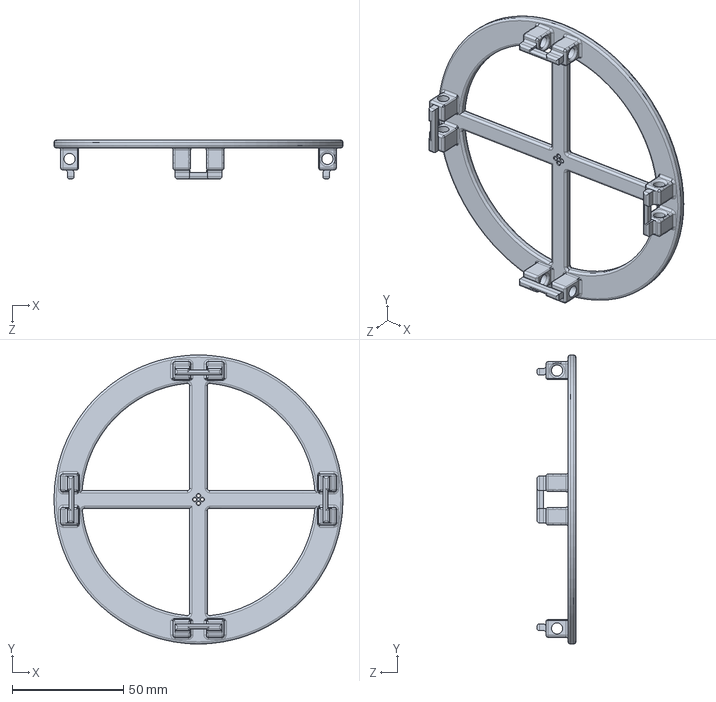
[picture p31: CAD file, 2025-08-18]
CAD Drawing_2025.08.18/Lower platform.SLDPRT
130.0 x 130.0 x 17.5 mm

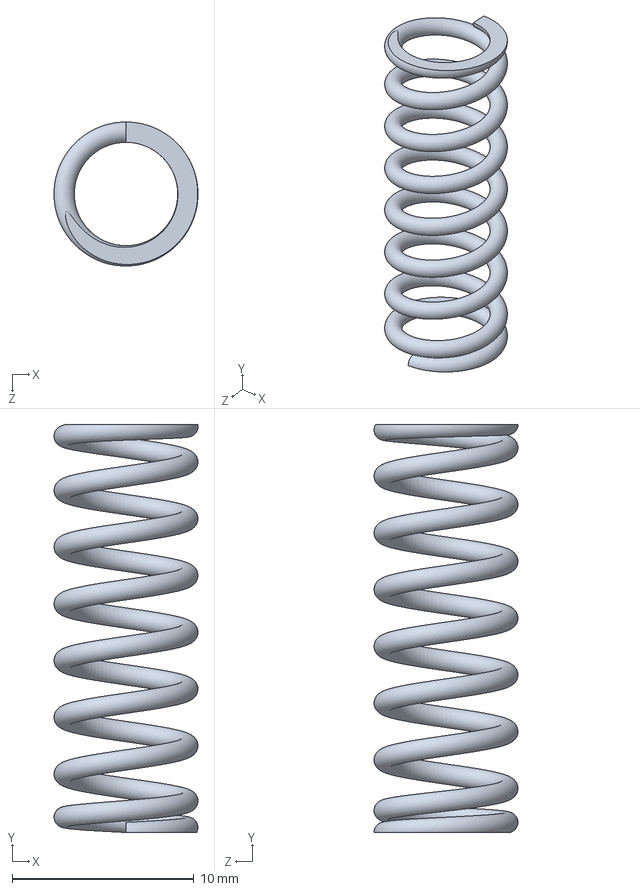
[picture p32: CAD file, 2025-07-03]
initial guessing of gliding mechanism/air-actuated deployment mechanism/lever spring.SLDPRT
7.92 x 22.4 x 7.92 mm

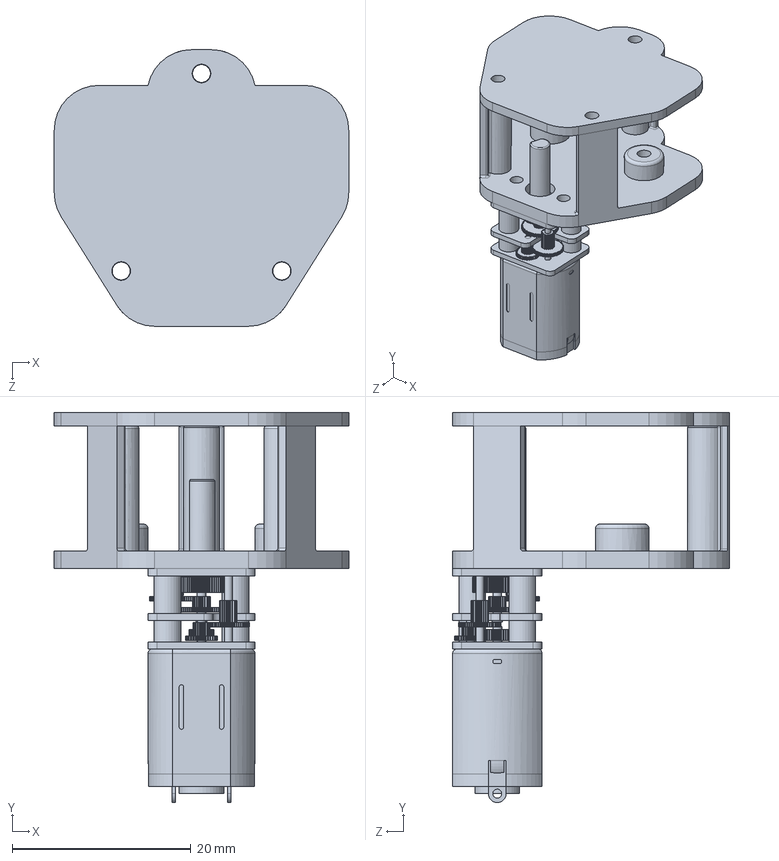
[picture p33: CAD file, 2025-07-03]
initial guessing of gliding mechanism/motor controlled wing mechanism/N20 motor.SLDPRT
33.0 x 43.7 x 31.0 mm

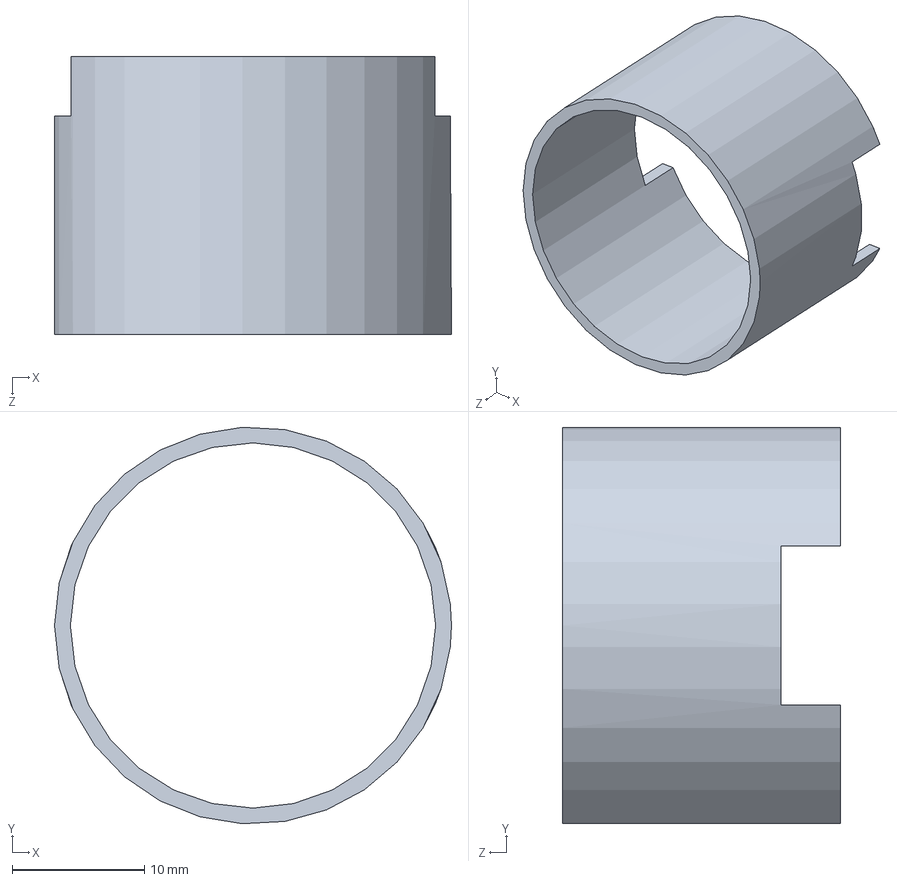
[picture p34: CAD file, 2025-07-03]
motor-to-electromagnetic clutch connection design/Servo Part1.SLDPRT
30.0 x 30.0 x 21.0 mm

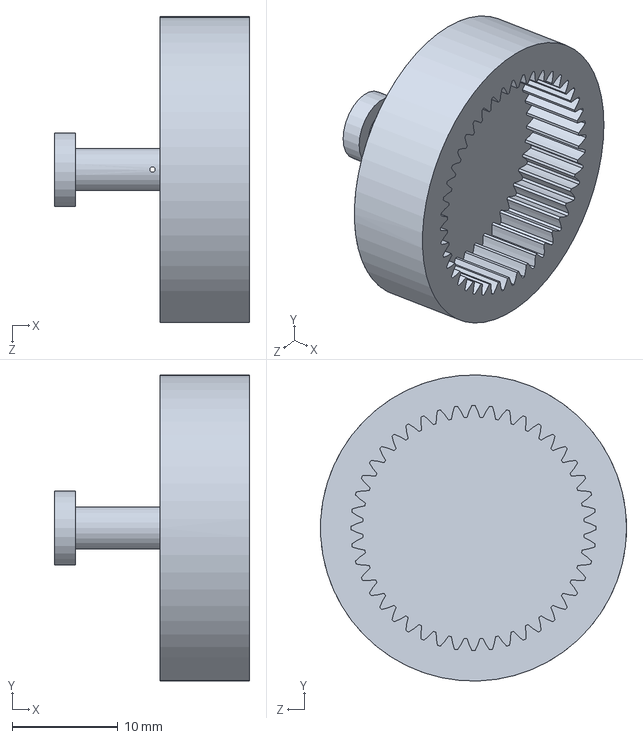
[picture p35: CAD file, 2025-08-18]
CAD Drawing_2025.08.18/Outer servo connector.SLDPRT
18.5 x 29.0 x 29.0 mm

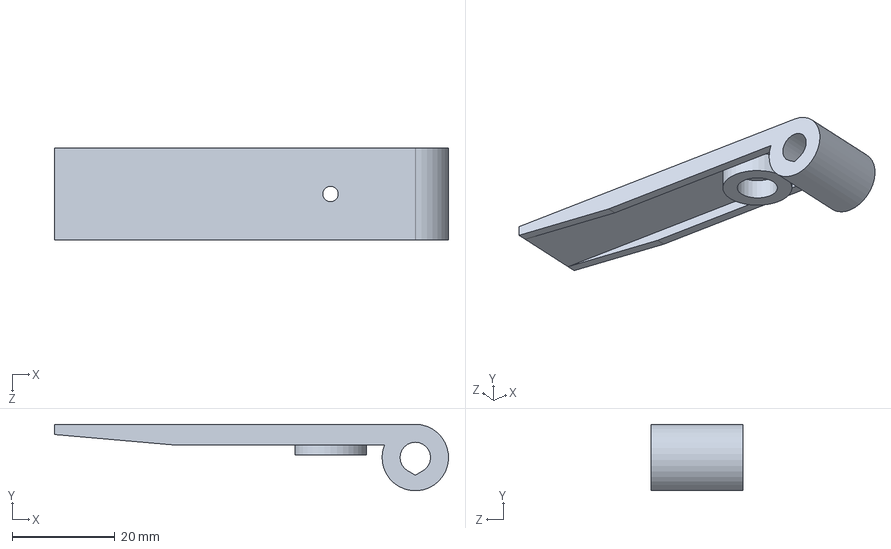
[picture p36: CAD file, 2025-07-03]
initial guessing of gliding mechanism/air-actuated deployment mechanism/lever.SLDPRT
76.7 x 12.9 x 18.0 mm

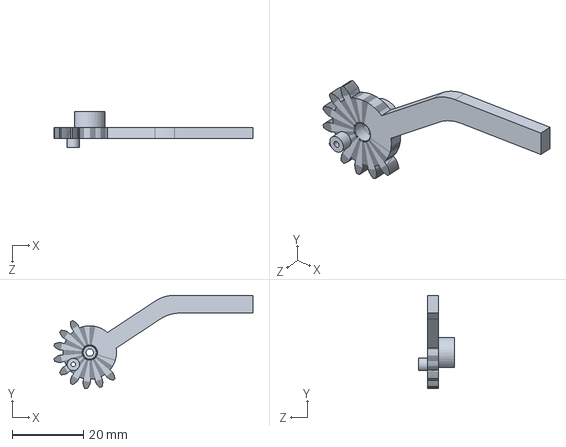
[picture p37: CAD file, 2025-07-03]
initial guessing of gliding mechanism/motor controlled wing mechanism/motor Spur_M1.2_Pa22_Z151.SLDPRT
55.9 x 26.3 x 10.0 mm

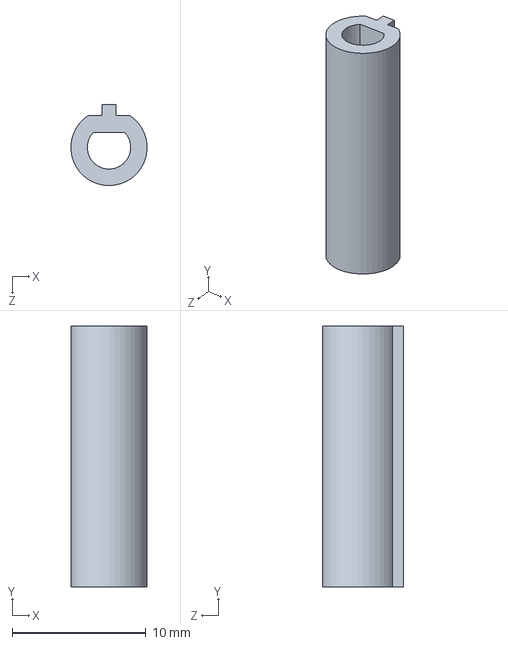
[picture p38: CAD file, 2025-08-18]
CAD Drawing_2025.08.18/Inner servo connector.SLDPRT
5.69 x 19.5 x 6.07 mm

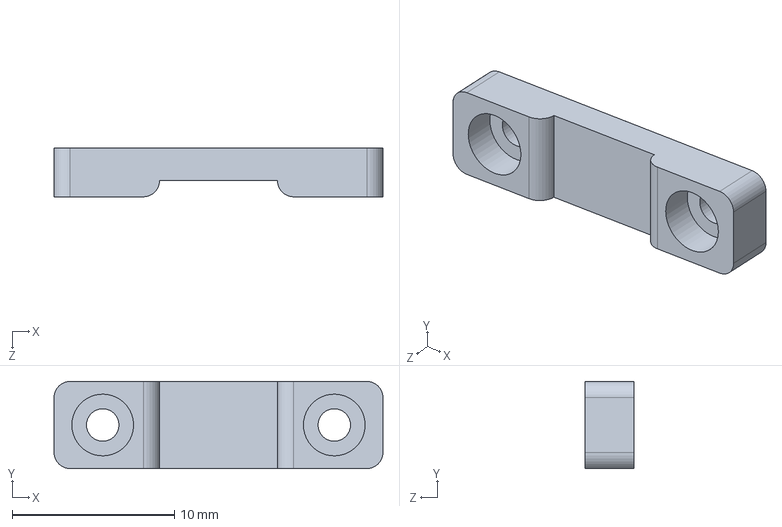
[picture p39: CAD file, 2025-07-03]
initial guessing of gliding mechanism/motor controlled wing mechanism/motor Part 3.SLDPRT
20.3 x 5.37 x 3.00 mm

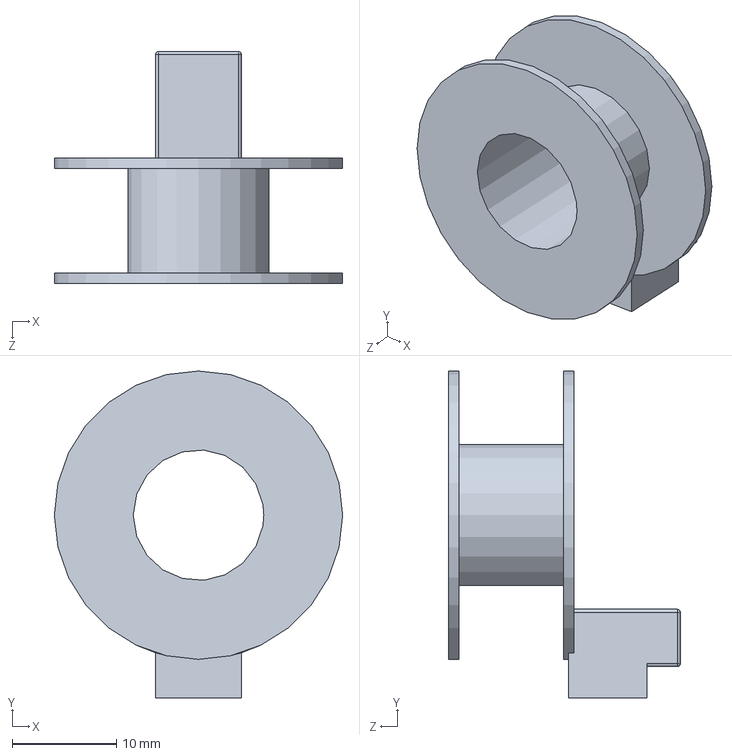
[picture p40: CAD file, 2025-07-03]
motor-to-electromagnetic clutch connection design/Servo Part3.SLDPRT
27.6 x 31.3 x 22.2 mm

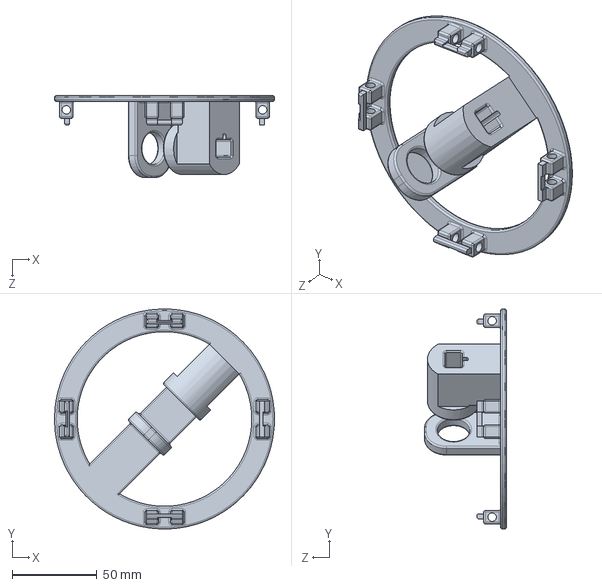
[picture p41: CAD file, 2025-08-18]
CAD Drawing_2025.08.18/Upper platform.SLDPRT
130.0 x 129.9 x 48.5 mm

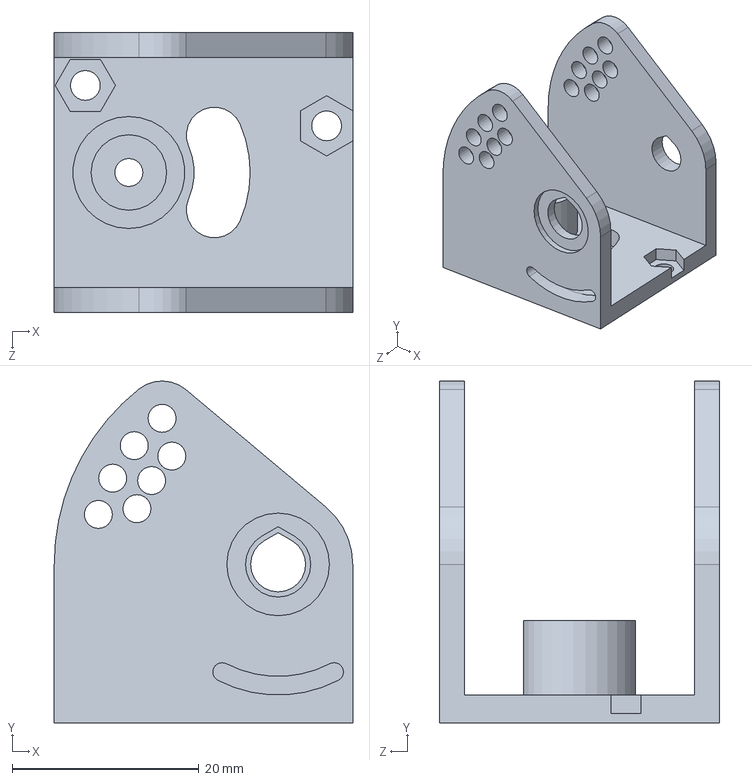
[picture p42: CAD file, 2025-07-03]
initial guessing of gliding mechanism/air-actuated deployment mechanism/lever body_3d.SLDPRT
32.0 x 36.7 x 30.0 mm

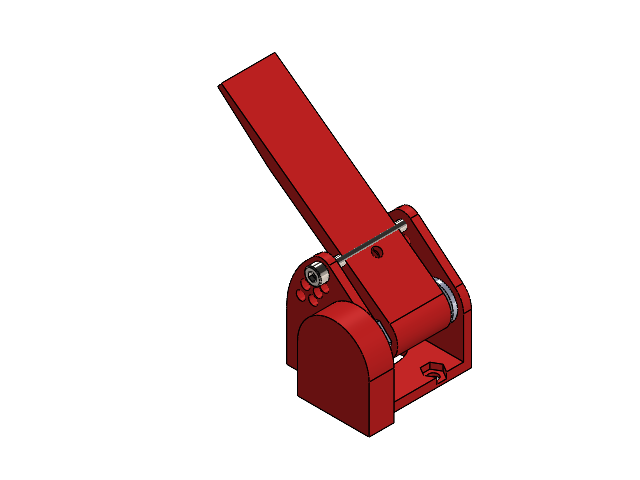
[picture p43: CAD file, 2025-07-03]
initial guessing of gliding mechanism/air-actuated deployment mechanism/lever assemble.SLDASM
body_3d
potentiometer
leva
socket head cap screw_am
nut^leva_embrague
Part3^leva_embrague
cover
133729 - Opruga obaraca kundaka

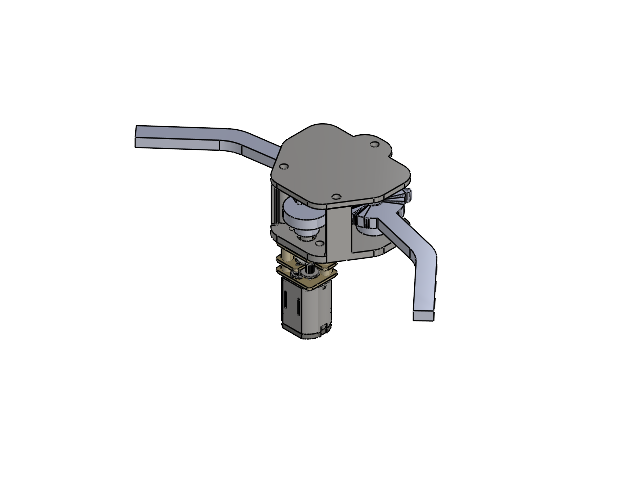
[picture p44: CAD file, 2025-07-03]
initial guessing of gliding mechanism/motor controlled wing mechanism/Wing Mechanism.SLDASM
N20 motor
Spur_M1.2_Pa22_Z151
Spur_M1.2_Pa22_Z1512
motor mount 01

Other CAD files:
motor-to-electromagnetic clutch connection design/Assembled servo.SLDASM
motor-to-electromagnetic clutch connection design/Assmbled with connector.SLDASM
motor-to-electromagnetic clutch connection design/Outer servo connector.SLDPRT
initial guessing of gliding mechanism/air-actuated deployment mechanism/lever cover.SLDPRT
CAD Drawing_2025.08.18/Nut fastener.SLDPRT
initial guessing of gliding mechanism/air-actuated deployment mechanism/lever potentiometer.SLDPRT
initial guessing of gliding mechanism/motor controlled wing mechanism/motor Spur_M1.2_Pa22_Z1512.SLDPRT
initial guessing of gliding mechanism/motor controlled wing mechanism/motor mount 01.SLDPRT
motor-to-electromagnetic clutch connection design/Inner servo connector.SLDPRT
motor-to-electromagnetic clutch connection design/N20 motor1.SLDPRT
motor-to-electromagnetic clutch connection design/Servo Part2.SLDPRT
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

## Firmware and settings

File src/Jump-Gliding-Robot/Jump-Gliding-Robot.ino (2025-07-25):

#include <ArduinoBLE.h>
#include "Arduino_BMI270_BMM150.h"
#include <Wire.h>
#include <Servo.h>
#include "include.h"
#include "SerialServo.h"

Servo servo1;
Servo servo2;

// BLE characteristics
BLEService sensorService("180F");
BLEByteCharacteristic servoCommandCharacteristic("2A19", BLEWrite);
BLECharacteristic imuDataCharacteristic("2A58", BLENotify, 36);

unsigned long previousMillis = 0;
const long interval = 50;
const int motorPin = 3;     // D3 pin controls the MOSFET gate for the 6V motor
const int clutchPin = 4;    // D4 pin controls the MOSFET gate for the 24V electromagnetic clutch

void setup() {
  Serial1.begin(115200);
  Wire.begin();
  servo1.attach(9);   // D9 pin controls a potential future servo motor
  servo2.attach(10);  // D10 pin controls a potential future servo motor

  // Initialize clutch and motor
  pinMode(motorPin, OUTPUT);
  pinMode(clutchPin, OUTPUT);
   digitalWrite(clutchPin, LOW);
   digitalWrite(motorPin, LOW);

  // Initialize Bluetooth
  if (!BLE.begin()) {
    while (1);
  }
  BLE.setLocalName("Nano33BLE_IMU");
  BLE.setAdvertisedService(sensorService);
  sensorService.addCharacteristic(servoCommandCharacteristic);
  sensorService.addCharacteristic(imuDataCharacteristic);
  BLE.addService(sensorService);
  BLE.advertise();

  // Initialize potential future IMU usage
  if (!IMU.begin()) {
    while (1);
  }
}
  // Function to send IMU data (potential future use)
void sendIMUData() {
  float ax, ay, az, gx, gy, gz, mx, my, mz;

  if (IMU.accelerationAvailable()) IMU.readAcceleration(ax, ay, az);
  if (IMU.gyroscopeAvailable()) IMU.readGyroscope(gx, gy, gz);
  if (IMU.magneticFieldAvailable()) IMU.readMagneticField(mx, my, mz);

  byte imuData[36];
  memcpy(&imuData[0], &ax, 4);
  memcpy(&imuData[4], &ay, 4);
  memcpy(&imuData[8], &az, 4);
  memcpy(&imuData[12], &gx, 4);
  memcpy(&imuData[16], &gy, 4);
  memcpy(&imuData[20], &gz, 4);
  memcpy(&imuData[24], &mx, 4);
  memcpy(&imuData[28], &my, 4);
  memcpy(&imuData[32], &mz, 4);

  imuDataCharacteristic.writeValue(imuData, 36);
}
void loop() {
  BLEDevice central = BLE.central();

  if (central) {
    while (central.connected()) {
      if (servoCommandCharacteristic.written()) {
        byte command = servoCommandCharacteristic.value();
        // When input '1', send automatic pull and release commands
       if (command == 1) {
          // Pull rope
         digitalWrite(motorPin, HIGH);   // Start motor rotation
         digitalWrite(clutchPin, HIGH);  // Power clutch to prepare for pulling
          delay(5000);                   // Run motor for a few seconds
          // Release rope 
          digitalWrite(motorPin, LOW);  // Cut power to motor
          digitalWrite(clutchPin, HIGH);  // Cut power to clutch to release
        }

        // When input '2', for timing tests, start motor and clutch
        else if (command == 2) {
        // Pull rope 
         digitalWrite(motorPin, HIGH);  // Start motor rotation
         digitalWrite(clutchPin, HIGH); // Power clutch to prepare for pullin
        } 

        // When input '3', currently unused; may control gliding in future
        else if (command == 3) {
          LobotSerialServoMove(Serial1, 1, 400, 800);
          LobotSerialServoMove(Serial1, 2, 400, 800);
        }  
        
        // When input '4', currently unused; may control gliding in future
        else if (command == 4) {
          LobotSerialServoMove(Serial1, 1, 800, 400);
          LobotSerialServoMove(Serial1, 2, 800, 400);
        }
      }  
      unsigned long currentMillis = millis();
      if (currentMillis - previousMillis >= interval) {
        previousMillis = currentMillis;
        sendIMUData();
      }
    }
  }
}

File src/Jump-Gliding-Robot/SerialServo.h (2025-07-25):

#include "include.h"

// Checksum
byte LobotCheckSum(byte buf[])
{
  byte i;
  uint16_t temp = 0;
  for (i = 2; i < buf[3] + 2; i++) {
    temp += buf[i];
  }
  temp = ~temp;
  i = (byte)temp;
  return i;
}

// Parse received data packet and return result
int LobotSerialServoReceiveHandle(HardwareSerial &SerialX, byte *ret)
{
  bool frameStarted = false;
  bool receiveFinished = false;
  byte frameCount = 0;
  byte dataCount = 0;
  byte dataLength = 2;
  byte rxBuf;
  byte recvBuf[32];
  byte i;

  while (SerialX.available()) {
    rxBuf = SerialX.read();
    delayMicroseconds(100);
    if (!frameStarted) {
      if (rxBuf == LOBOT_SERVO_FRAME_HEADER) {
        frameCount++;
        if (frameCount == 2) {
          frameCount = 0;
          frameStarted = true;
          dataCount = 1;
        }
      }
      else {
        frameStarted = false;
        dataCount = 0;
        frameCount = 0;
      }
    }
    if (frameStarted) {
      recvBuf[dataCount] = (uint8_t)rxBuf;
      if (dataCount == 3) {
        dataLength = recvBuf[dataCount];
        if (dataLength < 3 || dataCount > 7) {
          dataLength = 2;
          frameStarted = false;
        }
      }
      dataCount++;
      if (dataCount == dataLength + 3) {

        if (LobotCheckSum(recvBuf) == recvBuf[dataCount - 1]) {

          frameStarted = false;
          memcpy(ret, recvBuf + 4, dataLength);
          return 1;
        }
        return -1;
      }
    }
  }
  return 0;
}

// Write new servo ID
void LobotSerialServoSetID(HardwareSerial &SerialX, uint8_t oldID, uint8_t newID)
{
  byte buf[7];
  buf[0] = buf[1] = LOBOT_SERVO_FRAME_HEADER;
  buf[2] = oldID;
  buf[3] = 4;
  buf[4] = LOBOT_SERVO_ID_WRITE;
  buf[5] = newID;
  buf[6] = LobotCheckSum(buf);
  SerialX.write(buf, 7);
}

// Control servo to move to a position over a specified time
void LobotSerialServoMove(HardwareSerial &SerialX, uint8_t id, int16_t position, uint16_t time)
{
  byte buf[10];
  if (position < 0)
    position = 0;
  if (position > 1000)
    position = 1000;
  buf[0] = buf[1] = LOBOT_SERVO_FRAME_HEADER;
  buf[2] = id;
  buf[3] = 7;
  buf[4] = LOBOT_SERVO_MOVE_TIME_WRITE;
  buf[5] = GET_LOW_BYTE(position);
  buf[6] = GET_HIGH_BYTE(position);
  buf[7] = GET_LOW_BYTE(time);
  buf[8] = GET_HIGH_BYTE(time);
  buf[9] = LobotCheckSum(buf);
  SerialX.write(buf, 10);
}

// Read servo ID
int LobotSerialServoReadID(HardwareSerial &SerialX)
{
  int count = 10000;
  int ret;
  byte buf[6];
  
  buf[0] = buf[1] = LOBOT_SERVO_FRAME_HEADER;
  buf[2] = ID_ALL;  // ID_ALL is 254, which broadcasts to all servos; useful for discovering unknown IDs
  buf[3] = 3;
  buf[4] = LOBOT_SERVO_ID_READ;
  buf[5] = LobotCheckSum(buf);
  SerialX.write(buf, 6);

  while (SerialX.available())
    SerialX.read();

  while (!SerialX.available()) {
    count -= 1;
    if (count < 0)
      return -2048;
  }

  if (LobotSerialServoReceiveHandle(SerialX, buf) > 0)
    ret = (int16_t)BYTE_TO_HW(0x00, buf[1]);
  else
    ret = -2048;
  return ret;
}

// Read servo position
int LobotSerialServoReadPosition(HardwareSerial &SerialX, uint8_t id)
{
  int count = 10000;
  int ret;
  byte buf[6];

  buf[0] = buf[1] = LOBOT_SERVO_FRAME_HEADER;
  buf[2] = id;
  buf[3] = 3;
  buf[4] = LOBOT_SERVO_POS_READ;
  buf[5] = LobotCheckSum(buf);
  SerialX.write(buf, 6);
  
  while (SerialX.available())
    SerialX.read();

  while (!SerialX.available()) {
    count -= 1;
    if (count < 0)
      return -2048;
  }

  if (LobotSerialServoReceiveHandle(SerialX, buf) > 0)
    ret = (int16_t)BYTE_TO_HW(buf[2], buf[1]);
  else
    ret = -2048;
  return ret;
}

// Read angle offset
int LobotSerialServoReadDev(HardwareSerial &SerialX, uint8_t id)
{
  int count = 10000;
  int ret;
  byte buf[6];

  buf[0] = buf[1] = LOBOT_SERVO_FRAME_HEADER;
  buf[2] = id;
  buf[3] = 3;
  buf[4] = LOBOT_SERVO_ANGLE_OFFSET_READ;
  buf[5] = LobotCheckSum(buf);
  SerialX.write(buf, 6);
  
  while (SerialX.available())
    SerialX.read();

  while (!SerialX.available()) {
    count -= 1;
    if (count < 0)
      return -2048;
  }

  if (LobotSerialServoReceiveHandle(SerialX, buf) > 0)
    ret = (int16_t)BYTE_TO_HW(buf[2], buf[1]);
  else
    ret = -2048;
  return ret;
}

// Read rotation range (min and max angles)
int retL;
int retH;
int LobotSerialServoReadAngleRange(HardwareSerial &SerialX, uint8_t id)
{
  int count = 10000;
  int ret;
  byte buf[6];

  buf[0] = buf[1] = LOBOT_SERVO_FRAME_HEADER;
  buf[2] = id;
  buf[3] = 3;
  buf[4] = LOBOT_SERVO_ANGLE_LIMIT_READ;
  buf[5] = LobotCheckSum(buf);
  SerialX.write(buf, 6);
  
  while (SerialX.available())
    SerialX.read();

  while (!SerialX.available()) {
    count -= 1;
    if (count < 0)
      return -2048;
  }

  if (LobotSerialServoReceiveHandle(SerialX, buf) > 0) {
    retL = (int16_t)BYTE_TO_HW(buf[2], buf[1]);
    retH = (int16_t)BYTE_TO_HW(buf[4], buf[3]);
  }
  else
    ret = -2048;
  return ret;
}

// Read input voltage
int LobotSerialServoReadVin(HardwareSerial &SerialX, uint8_t id)
{
  int count = 10000;
  int ret;
  byte buf[6];

  buf[0] = buf[1] = LOBOT_SERVO_FRAME_HEADER;
  buf[2] = id;
  buf[3] = 3;
  buf[4] = LOBOT_SERVO_VIN_READ;
  buf[5] = LobotCheckSum(buf);
  SerialX.write(buf, 6);

  while (SerialX.available())
    SerialX.read();

  while (!SerialX.available()) {
    count -= 1;
    if (count < 0)
      return -2048;
  }

  if (LobotSerialServoReceiveHandle(SerialX, buf) > 0)
    ret = (int16_t)BYTE_TO_HW(buf[2], buf[1]);
  else
    ret = -2049;
    
  return ret;
}

// Read voltage range (min and max VIN)
int vinL;
int vinH;
int LobotSerialServoReadVinLimit(HardwareSerial &SerialX, uint8_t id)
{
  int count = 10000;
  int ret;
  byte buf[6];

  buf[0] = buf[1] = LOBOT_SERVO_FRAME_HEADER;
  buf[2] = id;
  buf[3] = 3;
  buf[4] = LOBOT_SERVO_VIN_LIMIT_READ;
  buf[5] = LobotCheckSum(buf);
  SerialX.write(buf, 6);
  
  while (SerialX.available())
    SerialX.read();

  while (!SerialX.available()) {
    count -= 1;
    if (count < 0)
      return -2048;
  }

  if (LobotSerialServoReceiveHandle(SerialX, buf) > 0) {
    vinL = (int16_t)BYTE_TO_HW(buf[2], buf[1]); 
    vinH = (int16_t)BYTE_TO_HW(buf[4], buf[3]);
  }
  else
    ret = -2048;
  return ret;
}

// Read maximum temperature threshold
int LobotSerialServoReadTempLimit(HardwareSerial &SerialX, uint8_t id)
{
  int count = 10000;
  int ret;
  byte buf[6];

  buf[0] = buf[1] = LOBOT_SERVO_FRAME_HEADER;
  buf[2] = id;
  buf[3] = 3;
  buf[4] = LOBOT_SERVO_TEMP_MAX_LIMIT_READ;
  buf[5] = LobotCheckSum(buf);
  SerialX.write(buf, 6);

  while (SerialX.available())
    SerialX.read();

  while (!SerialX.available()) {
    count -= 1;
    if (count < 0)
      return -2048;
  }

  if (LobotSerialServoReceiveHandle(SerialX, buf) > 0)
    ret = (int16_t)BYTE_TO_HW(0x00, buf[1]);
  else
    ret = -2049;
    
  return ret;
}
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
